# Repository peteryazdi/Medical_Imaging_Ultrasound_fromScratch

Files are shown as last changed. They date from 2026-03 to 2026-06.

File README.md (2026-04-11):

# Multi-Channel Ultrasound Imaging Device

## Overview

This repository documents the design and development of a custom ultrasound imaging platform. The system progresses from a single-channel 5 MHz analog front end to a multi-channel digital beamforming system capable of acquiring raw RF echo data, processing it on an FPGA, and producing ultrasound images.

The project covers transducer characterization, high-voltage pulse generation, low-noise receive electronics, analog-to-digital conversion, and FPGA-based signal processing.

---

## Current Status

**Rev 0 complete. Rev 1 schematic complete — PCB layout in progress.**

### Completed

- Two 5 MHz thickness-gauge transducers purchased and characterized
- Center frequency confirmed at 5.000 MHz via oscilloscope cursor measurement
- Both channels verified functional using AD2 impulse excitation
- Ring-down and cross-coupling observed through gel-coupled water path
- Rev 1 8-channel Tx/Rx schematic designed and ERC-clean in KiCad

### Rev 1 Hardware Design

The Rev 1 board is an 8-channel transmit pulser with passive receive protection, designed around the MD1213 gate driver and TC6320 complementary MOSFET pair (Microchip).

**Per channel:**
- MD1213 dual MOSFET gate driver (VQFN-12, ±5V bipolar supply)
- TC6320 N+P MOSFET pair (SOIC-8, 200V BVDSS)
- 10nF/200V AC coupling capacitors (OUTA→GP, OUTB→GN)
- 1μF/200V storage capacitors per HV rail with 1MΩ bleed resistors
- 0.47μF/16V bypass capacitors on ±5V driver supply
- Back-to-back clamp diodes (300V rated) for Tx protection
- 200Ω series resistor + back-to-back clamp diodes to GND for Rx protection
- 1MΩ DC bias resistor on Tx/Rx node
- 10kΩ pull-down on OE (outputs disabled by default)
- SMA vertical connector per channel (SMA-to-Lemo adapter for current transducers)

**Power supply (bench supply fed via screw terminals):**
- ±100V HV rails: 10μF electrolytic + 1μF ceramic + 1MΩ bleed per rail
- ±5V LV rails: 10μF ceramic per rail
- Dedicated GND screw terminal

**Control and I/O:**
- 2×14 pin header for FPGA connection (8× INA, INB, OE + TRIG_OUT, TRIG_IN, GND)
- 33Ω series resistors on all logic inputs
- 2×8 pin header for Rx output (8 channels with alternating GND pins)
- LED indicators: +5V power (green), +100V power (red), trigger activity (yellow), OE status (blue)

---

## Key Specifications

| Parameter | Value |
|---|---|
| Transducer frequency | 5 MHz |
| Pulse type | Bipolar, 1 cycle (200 ns) |
| HV supply range | ±5V to ±100V (variable via bench supply) |
| Number of Tx/Rx channels | 8 |
| MOSFET breakdown voltage | 200V (TC6320) |
| Gate drive swing | ±5V (10V total, AC coupled) |
| Rise time (500pF load) | ~8 ns |
| Peak current (100V, 7Ω RDS) | 14.3A instantaneous |
| Rx clamp voltage | ±0.7V |
| Dead zone (200Ω Rx series) | < 0.1 mm |
| Max imaging depth at 7700 Hz PRF | 10 cm |
| Axial resolution (theoretical) | 0.154 mm |
| Power dissipation per TC6320 | ~17 mW |

---

## Development Roadmap

| Revision | Scope | Status |
|---|---|---|
| Rev 0 | Transducer characterization, initial impulse testing | Complete |
| Rev 1 | 8-channel Tx pulser + passive Rx protection, scope-based echo measurement | Schematic complete, PCB layout in progress |
| Rev 2 | Multi-channel Rx analog chain (LNA, bandpass filter, TGC) on separate board | Planned |
| Rev 3 | ADC integration, digitization of RF echo data | Planned |
| Rev 4 | FPGA DSP pipeline: filtering, envelope detection, delay-and-sum beamforming | Planned |
| Rev 5 | A-scan and B-scan visualization, phantom imaging | Planned |

---

## Hardware

### Transducers
- 5 MHz thickness-gauge transducers (Amazon, 2 units)
- Lemo connectors, connected via SMA-to-Lemo adapter cables
- Used for both Tx and Rx in pitch-catch configuration

### Test Equipment
- Digilent Analog Discovery 2 (AD2) — initial low-voltage impulse source
- Tektronix TDS 2014 oscilloscope — waveform capture and measurement
- Ultrasound coupling gel

---

## Physics Reference

| Quantity | Formula | Value at 5 MHz |
|---|---|---|
| Wavelength | λ = c / f | 0.308 mm |
| Axial resolution | c / (2f) per cycle | 0.154 mm |
| Depth from echo time | d = ct / 2 | 0.77 mm/μs |
| Max PRF | c / (2 × d_max) | 7700 Hz at 10 cm |
| Attenuation | ~0.5 dB/cm/MHz | 2.5 dB/cm |
| Sound speed (soft tissue) | — | 1540 m/s |

---

## Safety

This is an educational project, not a certified medical device. The system is not intended for diagnostic or clinical use. High-voltage circuits require appropriate safety practices. All testing is performed on phantoms, water-path setups, and non-clinical targets.

---

## Author

Peter Yazdi — peteryazdi@gmail.com

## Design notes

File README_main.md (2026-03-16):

# Multi-Channel Ultrasound Imaging Device

## Overview

This repository documents the design and development of an ultrasound imaging platform intended for **educational purposes**. The long-term goal is to progress from a **single-channel 5 MHz analog ultrasound front end** to a **multi-channel digital beamforming system** capable of capturing raw radio-frequency (RF) echo data, transferring that data into an FPGA, and ultimately producing a visual ultrasound image.

This project is motivated by an interest in:

- medical imaging physics
- piezoelectric transducers and wave propagation
- analog front-end design for weak, high-frequency signals
- high-voltage pulse generation
- analog-to-digital conversion at ultrasound frequencies
- FPGA-based signal processing and beamforming
- end-to-end imaging system architecture

The project is intentionally staged so that each revision builds practical understanding of a specific subsystem before the next level of complexity is introduced. The first milestone is not full imaging, but rather a **working single-channel transmit/receive analog chain up to the ADC**.

---

## Project Purpose

Modern ultrasound imaging systems are complex, highly integrated platforms that bring together acoustics, high-voltage excitation, low-noise analog electronics, high-speed data acquisition, digital signal processing, and image formation algorithms. This project is driven by the goal of understanding and developing these core subsystems from first principles rather than treating medical ultrasound as a closed, inaccessible technology. The purpose of this repository is to serve as a technical foundation for the physics, engineering, and implementation of a medical imaging ultrasound device. As development progresses, the relevant branches will contain simulations, hardware schematics, firmware, software, and supporting documentation needed to study, build, and refine the system.

---

## Physics Background

## 1. What Ultrasound Is

Ultrasound refers to acoustic waves above the range of human hearing. In imaging systems, ultrasound commonly operates in the megahertz range. These are **longitudinal pressure waves** that propagate through matter by alternating regions of compression and rarefaction.

For soft tissue, a standard approximation for sound speed is:

```text
c ≈ 1540 m/s
```

The wavelength of ultrasound is related to frequency by:

```text
λ = c / f
```

So for a 5 MHz wave in soft tissue:

```text
λ ≈ 1540 / 5,000,000 ≈ 0.308 mm
```

That small wavelength is one of the reasons ultrasound can resolve relatively fine structures.

### Why frequency matters

Frequency is one of the most important design choices in ultrasound.

- **Higher frequency** gives better spatial resolution.
- **Lower frequency** penetrates deeper into material or tissue.

This project is beginning at **5 MHz** because it is a practical frequency for learning high-frequency analog design while still being low enough to work with relatively accessible components and transducers.

---

## 2. Acoustic Impedance and Echo Formation

Ultrasound imaging works because sound reflects at boundaries where material properties change.

The key parameter is **acoustic impedance**:

```text
Z = ρc
```

where:

- `ρ` is material density,
- `c` is sound speed in that material.

When an ultrasonic wave hits a boundary between two materials with different impedances, some energy is transmitted and some is reflected. A larger impedance mismatch produces a stronger reflection.

This is why interfaces such as:

- gel to skin,
- soft tissue to bone,
- soft tissue to air,

produce very different echo strengths.

### Reflection coefficient

For normal incidence, the reflected intensity fraction is:

```text
R = ((Z2 - Z1) / (Z2 + Z1))^2
```

This principle is central to imaging. The transducer sends a pulse, listens for returning echoes, and the **arrival time** of those echoes reveals depth.

### Time-of-flight depth estimation

If an echo is received after time `t`, then the reflector depth is approximately:

```text
d = ct / 2
```

The factor of 2 is present because the wave must travel to the target and back.

---

## 3. Piezoelectric Transducers

Ultrasound transducers are based on the **piezoelectric effect**.

A piezoelectric material can:

- mechanically deform when a voltage is applied,
- generate a voltage when mechanically deformed.

That means the same physical element can act as both:

- a **transmitter** of ultrasound,
- a **receiver** of echoes.

When driven electrically, the transducer vibrates and launches an acoustic wave into the medium. When an echo returns, the incoming pressure wave deforms the element and creates a measurable electrical signal.

In practice, a transducer is not an ideal source. It has:

- a resonant frequency,
- finite bandwidth,
- mechanical ringing,
- electrical capacitance,
- coupling losses,
- sensitivity limits,
- dependence on backing, damping, and matching layers.

---

## 4. Why Coupling Gel Matters

Air is a very poor acoustic coupling medium for most ultrasound applications because the impedance mismatch between air and solids/soft tissue is extreme. Much of the acoustic energy reflects immediately at an air gap.

Ultrasound gel is used to reduce that mismatch by replacing trapped air with a material that transmits sound much more effectively.

In this project, gel will be used for:

- improving contact between probe and test object,
- reducing front-surface losses,
- making echo experiments more repeatable.

---

## 5. Ringing, Pulses, and Resonance

A transducer is generally not driven with continuous AC for pulse-echo imaging. Instead, it is usually excited by a **very short high-voltage pulse** or a **very short burst**. That brief excitation causes the piezoelectric element to ring near its resonant frequency.

This is important:

- the **transmit circuit** does not need to output a long 5 MHz sine wave,
- instead, it needs to produce a fast, energetic excitation that launches a short ultrasonic pulse,
- after that, the system should quickly stop driving and begin listening.

A shorter transmit event generally helps produce a shorter acoustic pulse, which improves **axial resolution**. However, excessive ringing can make it harder to hear shallow echoes right after transmit.

---

## 6. A-Scan, B-Scan, and Beamforming

Ultrasound images are built from echoes.

### A-scan

An A-scan is the most basic ultrasound measurement. It shows echo amplitude versus time, or equivalently versus depth. This is the first imaging-style output this project should aim to obtain.

### B-scan

A B-scan is formed by collecting many A-scans across different lateral positions and mapping echo amplitude to brightness. This creates a 2D grayscale image.

At early stages, B-scan data can be obtained by:

- mechanically moving a single probe,
- or later by using a multi-element array.

### Beamforming

Beamforming is the process of delaying and summing signals from multiple elements to steer and focus the effective beam electronically. This is one of the major long-term digital goals of the project and the reason an FPGA is planned for later revisions.

---

## Engineering Concepts Being Applied

## 1. High-Voltage Transmit Pulse Generation

The transducer must be excited strongly enough to launch a detectable acoustic pulse. Because piezoelectric elements are relatively stiff electromechanical devices, transmit performance often benefits from fast, high-voltage pulses.

The transmit side of this project will investigate:

- how to generate a short, clean excitation pulse,
- how large that pulse must be for the purchased probe,
- whether a unipolar or bipolar pulser is more appropriate later,
- how to keep transmit energy from overwhelming the receive chain.

### Initial design philosophy

For early revisions, the focus is not yet on a production-grade pulser, but on a controlled experimental pulser that can:

- start at lower voltages,
- be measured safely on an oscilloscope,
- be increased gradually,
- and be correlated with received echo quality.

Because the transducer has no accessible full datasheet, the transmit voltage should not be assumed. It should be characterized experimentally.

---

## 2. Tx/Rx Switching

In many ultrasound systems, the same element is used for both transmission and reception. In that case, a **Tx/Rx switch** is required to:

- connect the transducer to the high-voltage pulser during transmit,
- isolate the low-noise receive path from the transmit pulse,
- reconnect the transducer to the receiver immediately after transmit.

For this project, an important practical note is that the currently purchased 5 MHz probe may already expose separate transmit and receive leads, as is common with some thickness-gauge-style probes. If that is confirmed experimentally, then the first revision may not require a traditional Tx/Rx switch.

That would simplify Rev 1 significantly and allow earlier focus on analog receive design.

---

## 3. Low-Noise Amplification (LNA)

Echoes received from a transducer are often very small compared with the transmit event that created them. The receive chain must recover weak high-frequency signals without burying them in circuit noise.

A **low-noise amplifier** is used near the front end to:

- boost very small signals early,
- improve signal-to-noise ratio,
- preserve weak echoes before later processing stages.

A good receive front end needs more than gain. It also needs:

- enough bandwidth for 5 MHz operation,
- low input-referred noise,
- stability,
- protection against overload,
- good power-supply decoupling,
- careful grounding and layout.

This project will study not only which amplifier topology is appropriate, but also how much gain should be distributed across stages.

---

## 4. Band-Pass Filtering

A receive signal contains not only useful echoes but also:

- electrical feedthrough from the transmit event,
- broadband noise,
- out-of-band interference,
- ringing and parasitic response.

A **band-pass filter** centered around the probe’s effective operating band helps:

- suppress low-frequency drift,
- suppress high-frequency noise,
- isolate the echo band of interest,
- improve downstream ADC usage.

In this project, the filter design should eventually be informed by measured probe behavior rather than assumed nominal behavior.

---

## 5. Time Gain Compensation (TGC)

As ultrasound travels deeper into a medium, echo amplitude strength tends to decrease due to attenuation and spreading losses. A fixed-gain receiver may therefore represent shallow echoes well while burying deeper echoes in noise.

**Time Gain Compensation (TGC)** is a depth-dependent gain strategy. It increases gain as time passes after transmit so that later, deeper echoes are amplified more than early echoes.

Why this matters:

- shallow reflectors often produce strong echoes,
- deeper reflectors often produce much weaker echoes,
- without TGC, the dynamic range of the image can be poorly balanced.

---

## 6. Analog-to-Digital Conversion (ADC)

The ADC is the bridge between the analog and digital halves of the system.

Its job is to sample the RF echo waveform with enough:

- speed,
- resolution,
- timing integrity,
- and channel consistency.

### Why the ADC matters so much

If the sampling rate is too low, the RF waveform will be lost or aliased.
If the resolution is too low, weak echoes may disappear into quantization noise.
If clock quality is poor, timing jitter can significantly degrade measurements.

## 7. FPGA Processing

A microcontroller is useful for many embedded tasks, but high-speed multi-channel ultrasound processing rapidly becomes a parallel data problem.

An FPGA is attractive because it can:

- capture multiple high-speed digital streams in parallel,
- implement deterministic timing,
- apply channel delays for beamforming,
- perform filtering and envelope detection,
- support custom imaging pipelines.

---

## Proposed System Architecture

The long-term signal path of the project is expected to resemble:

```text
Transducer(s)
   → transmit pulser / Tx-Rx switching
   → receive protection
   → low-noise amplification
   → band-pass filtering
   → optional variable gain / TGC
   → ADC
   → FPGA capture and DSP
   → beamforming / envelope detection / scan conversion
   → host PC or display visualization
```

---

## Development Roadmap

The roadmap below reflects the intended progression of the project and is expected to evolve as real hardware data is collected.

## Rev 0 — Probe Characterization

Before committing to a final analog architecture, the purchased probe should be characterized experimentally.

### Objectives

- identify the wiring and determine whether Tx and Rx lines are truly separate,
- verify continuity and basic electrical behavior,
- apply low-voltage test excitation first,
- observe whether one transducer can excite the other in a controlled setup,
- estimate center frequency and ringing behavior on the oscilloscope,
- determine how strongly the probe couples through gel and simple test media,
- build confidence that the purchased hardware actually functions.

### Why this revision matters

This is the best way to avoid repeating a common failure mode from earlier ultrasound prototyping work: building too much circuitry around an unverified transducer.

---

## Rev 1 — Single-Channel Analog Front End Up to the ADC node

This is the first major hardware revision.

### Goals

- build a single-channel 5 MHz transmit circuit,
- excite the probe using a short high-voltage pulse,
- use the same physical probe housing for transmit and receive,
- exploit separate Tx/Rx leads if the probe already provides them,
- design a receive chain with:
  - input protection,
  - low-noise amplification,
  - band-pass filtering,
  - optional gain staging,
- produce a clean analog signal suitable for digitization (right up to the ADC)

### Key notes

- The transmit source should be a **short pulse**, not continuous AC drive.
- The transmit voltage must be determined experimentally because the probe lacks a reliable datasheet.
- Breadboarding high-frequency analog receive stages is likely to be unreliable; early PCB or at least very compact construction is preferred.
- If separate Tx and Rx leads are confirmed, a conventional Tx/Rx switch can be deferred.

### Expected output of Rev 1

- repeatable excitation waveform,
- measurable receive waveform,
- known gain structure,
- scoped analog echo response,
- candidate signal ready for digitization.

---

## Rev 1.5 — Measurement and Test Infrastructure

### Goals

- create repeatable test targets and phantoms,
- define standard oscilloscope measurement procedures,
- record pulse width, ringing time, noise floor, and echo amplitude,
- save captured waveforms for offline analysis,
- build scripts for plotting time-domain response.

### Why this should exist

A measurement workflow is as important as the circuit itself. Without repeatable tests, later changes in gain, filtering, layout, or transmit pulse shape will be difficult to compare objectively.

---

## Rev 2 — Multi-Channel-Capable Analog Expansion

Once the single-channel path is trusted, the analog architecture should begin evolving toward multi-channel scalability.

### Goals

- redesign the single-channel analog path with replication in mind,
- evaluate how power, grounding, and shielding scale across channels,
- preserve consistent gain and bandwidth across channels,
- consider whether separate daughterboards or modular front-end blocks improve debugging,
- maintain compatibility with later high-speed ADC integration.

### Design philosophy

Even if only one or two channels are populated initially, the analog architecture should be able to support multi-channel use.

---

## Rev 3 — ADC Integration

This revision introduces real digitization.

### Single-channel target

- choose an ADC appropriate for 5 MHz RF sampling,
- validate sample quality,
- confirm timing, logic levels, and data extraction,
- save raw RF data for offline analysis.

### Multi-channel target

- transition from one sampled channel to multiple synchronized channels,
- ensure the data format and interface can scale toward FPGA capture,
- verify that the communication architecture does not become the system bottleneck.

### Expected output

- stored digital RF traces,
- verified timing relationship between transmit and sampled receive data,
- understanding of data throughput requirements.

---

## Rev 4 — FPGA Communication and Beamforming Foundations

This stage includes looking into communication protocals and what is the appropiate peripheral for this project. After there will be FPGA programming to allow for beamforming the incoming raw RF data. 

### Goals

- establish reliable communication between ADC and FPGA,
- implement raw sample capture pipelines,
- buffer and move data correctly,
- begin digital filtering and basic signal conditioning,
- build the foundations for delay-and-sum beamforming,
- learn how raw RF data becomes an image pipeline.

### Why FPGA here

By this point, the project is no longer only analog electronics. It becomes a real-time digital system problem, and the FPGA becomes central to scaling the platform into a true imaging device.

---

## Rev 5 — Visualization

This stage turns measured and processed data into something interpretable.

### Goals

- visualize A-scan data first,
- progress toward B-scan style images,
- display results on a host computer or dedicated display,
- compare raw RF, envelope-detected, and beamformed outputs,
- build intuition for what the system is actually measuring.

This stage represents the transition from “ultrasound electronics” to “ultrasound imaging.”

---

## Branching and Repository Philosophy

This repository is expected to evolve using multiple development branches.

The structure will be the following:

- `main` will hold general readme
- `theory` will involve the theory behind the phsyics and engineering concepts required to understand this project
- `simulations/testing` will involve all simulations and tests with results during development
- `hardware` will involve hardware schematics and information of current status of project
- `software/firmware` will involve all SW and FW needed for project

To see the revisions stage by stage, there will be the following branches involving all relevant data:

- `rev0_characterization`
- `rev1_single_channel_analog`
- `rev2_multi_channel_analog`
- `rev3_adc_integration`
- `rev4_fpga_pipeline`
- `rev5_visualization`

This would allow another student or builder to walk through the project historically and understand how the design matured from one stage to the next.

---

## Safety and Scope

This is an educational engineering project, not a certified medical device.

Important scope notes:

- this repository is not intended for diagnostic or clinical use,
- high-voltage pulsing requires careful safety practices,
- analog front-end circuits can be damaged easily by poor grounding or excessive transmit energy,
- early testing should be performed on phantoms, water-path setups, or simple non-clinical targets.

---

## Repository Status

Current status: **planning and architecture phase**.

This README will be updated as the project progresses to include:

---

## Author

**Peter Yazdi**

For any questions, please feel free to email me at :  peteryazdi@gmail.com

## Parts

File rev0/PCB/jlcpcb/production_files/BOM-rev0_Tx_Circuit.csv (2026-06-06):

Comment | Designator | Footprint | LCSC | Quantity
LED_GREEN | D4 | LED_D3.0mm |  | 1
SMA Vertical | J8 | SMA_Amphenol_132134-10_Vertical |  | 1
470 ohm, 0.25W | R11 | R_Axial_DIN0207_L6.3mm_D2.5mm_P10.16mm_Horizontal |  | 1
GND | INB_GND_TP2 | TestPoint_THTPad_D1.5mm_Drill0.7mm |  | 1
TX_Node_1 | TX_1_TP1 | TestPoint_THTPad_D1.5mm_Drill0.7mm |  | 1
TC6320 | Q2 | SOIC-8_3.9x4.9mm_P1.27mm |  | 1
GND | TRIG_OUT_GND_TP1 | TestPoint_THTPad_D1.5mm_Drill0.7mm |  | 1
LED_GREEN | D1 | LED_D3.0mm |  | 1
LED_GREEN | D6 | LED_D3.0mm |  | 1
HV_N | HV_N_TP1 | TestPoint_THTPad_D1.5mm_Drill0.7mm |  | 1
1N5819 | D7 | D_DO-41_SOD81_P10.16mm_Horizontal |  | 1
1uF / 200V | C4 | C_1210_3225Metric |  | 1
470 ohm, 0.25W | R27 | R_Axial_DIN0207_L6.3mm_D2.5mm_P10.16mm_Horizontal |  | 1
Jumper_2pin | JP2 | PinHeader_1x02_P2.54mm_Vertical |  | 1
100K, 0.25W | R28 | R_Axial_DIN0207_L6.3mm_D2.5mm_P10.16mm_Horizontal |  | 1
HV_P | HV_P_TP1 | TestPoint_THTPad_D1.5mm_Drill0.7mm |  | 1
INB | INB_TP2 | TestPoint_THTPad_D1.5mm_Drill0.7mm |  | 1
1uF/250V | C11 | C_1210_3225Metric |  | 1
DRV_P5V | LV_P_TP1 | TestPoint_THTPad_D1.5mm_Drill0.7mm |  | 1
TC6320 | Q1 | SOIC-8_3.9x4.9mm_P1.27mm |  | 1
10K | R16 | R_0805_2012Metric |  | 1
10K | R9 | R_Axial_DIN0207_L6.3mm_D2.5mm_P10.16mm_Horizontal |  | 1
10K | R36 | R_0805_2012Metric |  | 1
GND | INA_GND_TP2 | TestPoint_THTPad_D1.5mm_Drill0.7mm |  | 1
MURS160 | D5 | D_SMA |  | 1
Screw_Terminal_01x02 | J3 | TerminalBlock_Phoenix_MKDS-3-2-5.08_1x02_P5.08mm_Horizontal |  | 1
Screw_Terminal_01x02 | J1 | TerminalBlock_Phoenix_MKDS-3-2-5.08_1x02_P5.08mm_Horizontal |  | 1
1uF/250V | C14 | C_1210_3225Metric |  | 1
Jumper_2pin | JP1 | PinHeader_1x02_P2.54mm_Vertical |  | 1
10uF/16V | C19 | CP_Radial_D5.0mm_P2.50mm |  | 1
1uF/250V | C17 | C_1210_3225Metric |  | 1
10nF/200V | C15 | C_0805_2012Metric |  | 1
10K | R13 | R_0805_2012Metric |  | 1
MURS160 | D10 | D_SMA |  | 1
Conn_02x05_Odd_Even | J5 | PinHeader_2x05_P2.54mm_Vertical |  | 1
10nF/200V | C9 | C_0805_2012Metric |  | 1
TX_Node_2 | TX_2_TP1 | TestPoint_THTPad_D1.5mm_Drill0.7mm |  | 1
10nF/200V | C12 | C_0805_2012Metric |  | 1
10K | R12 | R_0805_2012Metric |  | 1
DCWN03_05 | U3 | DCWN03_DIP24_8PIN |  | 1
10uF/200V | C1 | CP_Radial_D10.0mm_P5.00mm |  | 1
DRV_N5V | LV_N_TP1 | TestPoint_THTPad_D1.5mm_Drill0.7mm |  | 1
10uF/200V | C2 | CP_Radial_D10.0mm_P5.00mm |  | 1
SMA Vertical | J9 | SMA_Amphenol_132134-10_Vertical |  | 1
TRIG_OUT | TRIG_OUT_TP1 | TestPoint_THTPad_D1.5mm_Drill0.7mm |  | 1
INB | INB_TP1 | TestPoint_THTPad_D1.5mm_Drill0.7mm |  | 1
INA | INA_TP2 | TestPoint_THTPad_D1.5mm_Drill0.7mm |  | 1
GND | INB_GND_TP1 | TestPoint_THTPad_D1.5mm_Drill0.7mm |  | 1
MD1213 | U1 | MD1213_VQFN12_4x4_P0.8_EP1.7x1.7 |  | 1
0.47uF/50V | C16 | C_0805_2012Metric |  | 1
1uF/250V | C21 | C_1210_3225Metric |  | 1
GND | INA_GND_TP1 | TestPoint_THTPad_D1.5mm_Drill0.7mm |  | 1
10nF/200V | C18 | C_0805_2012Metric |  | 1
GND | TX_2_GND_TP1 | TestPoint_THTPad_D1.5mm_Drill0.7mm |  | 1
MD1213 | U2 | MD1213_VQFN12_4x4_P0.8_EP1.7x1.7 |  | 1
1N4007 | D8 | D_DO-41_SOD81_P10.16mm_Horizontal |  | 1
10K | R4 | R_Axial_DIN0207_L6.3mm_D2.5mm_P10.16mm_Horizontal |  | 1
GND | LV_N_GND_TP1 | TestPoint_THTPad_D1.5mm_Drill0.7mm |  | 1
GND | HV_P_GND_TP1 | TestPoint_THTPad_D1.5mm_Drill0.7mm |  | 1
0.47uF/50V | C7 | C_0805_2012Metric |  | 1
INA | INA_TP1 | TestPoint_THTPad_D1.5mm_Drill0.7mm |  | 1
10K | R31 | R_0805_2012Metric |  | 1
Screw_Terminal_01x02 | J4 | TerminalBlock_Phoenix_MKDS-3-2-5.08_1x02_P5.08mm_Horizontal |  | 1
MURS160 | D9 | D_SMA |  | 1
1N4007 | D3 | D_DO-41_SOD81_P10.16mm_Horizontal |  | 1
0.47uF/50V | C10 | C_0805_2012Metric |  | 1
GND | TX_1_GND_TP1 | TestPoint_THTPad_D1.5mm_Drill0.7mm |  | 1
LED_RED | D2 | LED_D3.0mm |  | 1
470 ohm, 0.25W | R30 | R_Axial_DIN0207_L6.3mm_D2.5mm_P10.16mm_Horizontal |  | 1
1ufF / 16V | C8 | C_Disc_D5.0mm_W2.5mm_P2.50mm |  | 1
Screw_Terminal_01x02 | J2 | TerminalBlock_Phoenix_MKDS-3-2-5.08_1x02_P5.08mm_Horizontal |  | 1
0.47uF/50V | C13 | C_0805_2012Metric |  | 1
1uF / 200V | C5 | C_1210_3225Metric |  | 1
GND | HV_N_GND_TP1 | TestPoint_THTPad_D1.5mm_Drill0.7mm |  | 1
MURS160 | D11 | D_SMA |  | 1
1uF / 16V | C20 | C_Disc_D5.0mm_W2.5mm_P2.50mm |  | 1
10K | R15 | R_0805_2012Metric |  | 1
GND | LV_P_GND_TP1 | TestPoint_THTPad_D1.5mm_Drill0.7mm |  | 1
1M / 0.25W | R2 | R_Axial_DIN0207_L6.3mm_D2.5mm_P10.16mm_Horizontal |  | 1
1M / 0.25W | R14 | R_Axial_DIN0207_L6.3mm_D2.5mm_P10.16mm_Horizontal |  | 1
1M / 0.25W | R32 | R_Axial_DIN0207_L6.3mm_D2.5mm_P10.16mm_Horizontal |  | 1
1M / 0.25W | R17 | R_Axial_DIN0207_L6.3mm_D2.5mm_P10.16mm_Horizontal |  | 1
1M / 0.25W | R37 | R_Axial_DIN0207_L6.3mm_D2.5mm_P10.16mm_Horizontal |  | 1
1M / 0.25W | R1 | R_Axial_DIN0207_L6.3mm_D2.5mm_P10.16mm_Horizontal |  | 1

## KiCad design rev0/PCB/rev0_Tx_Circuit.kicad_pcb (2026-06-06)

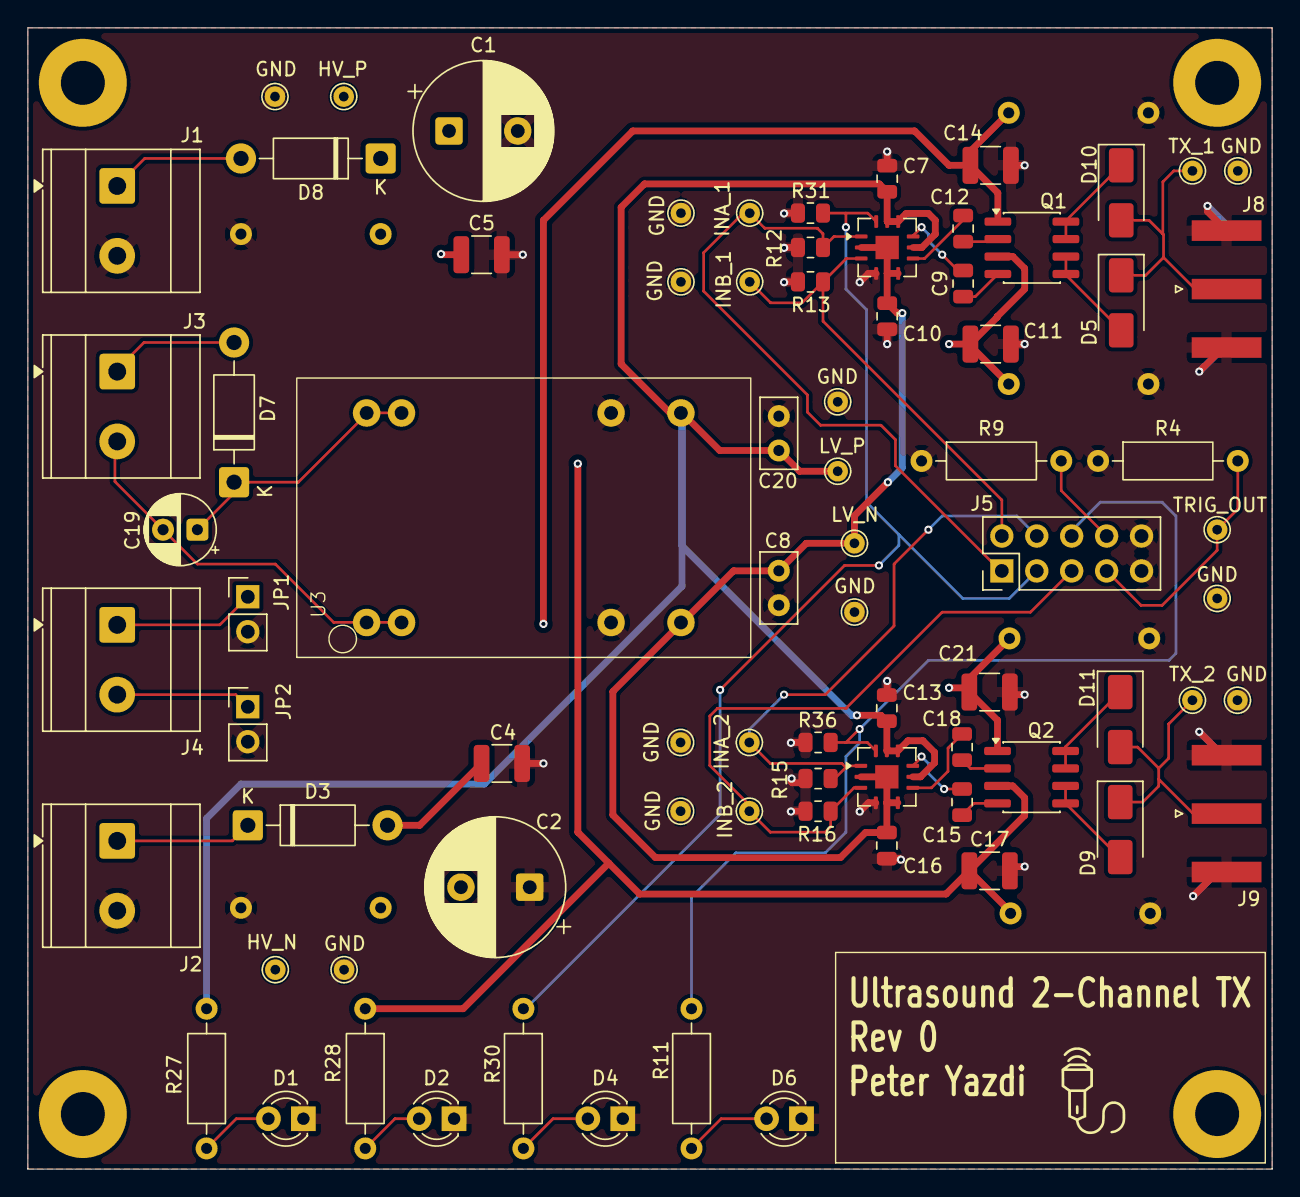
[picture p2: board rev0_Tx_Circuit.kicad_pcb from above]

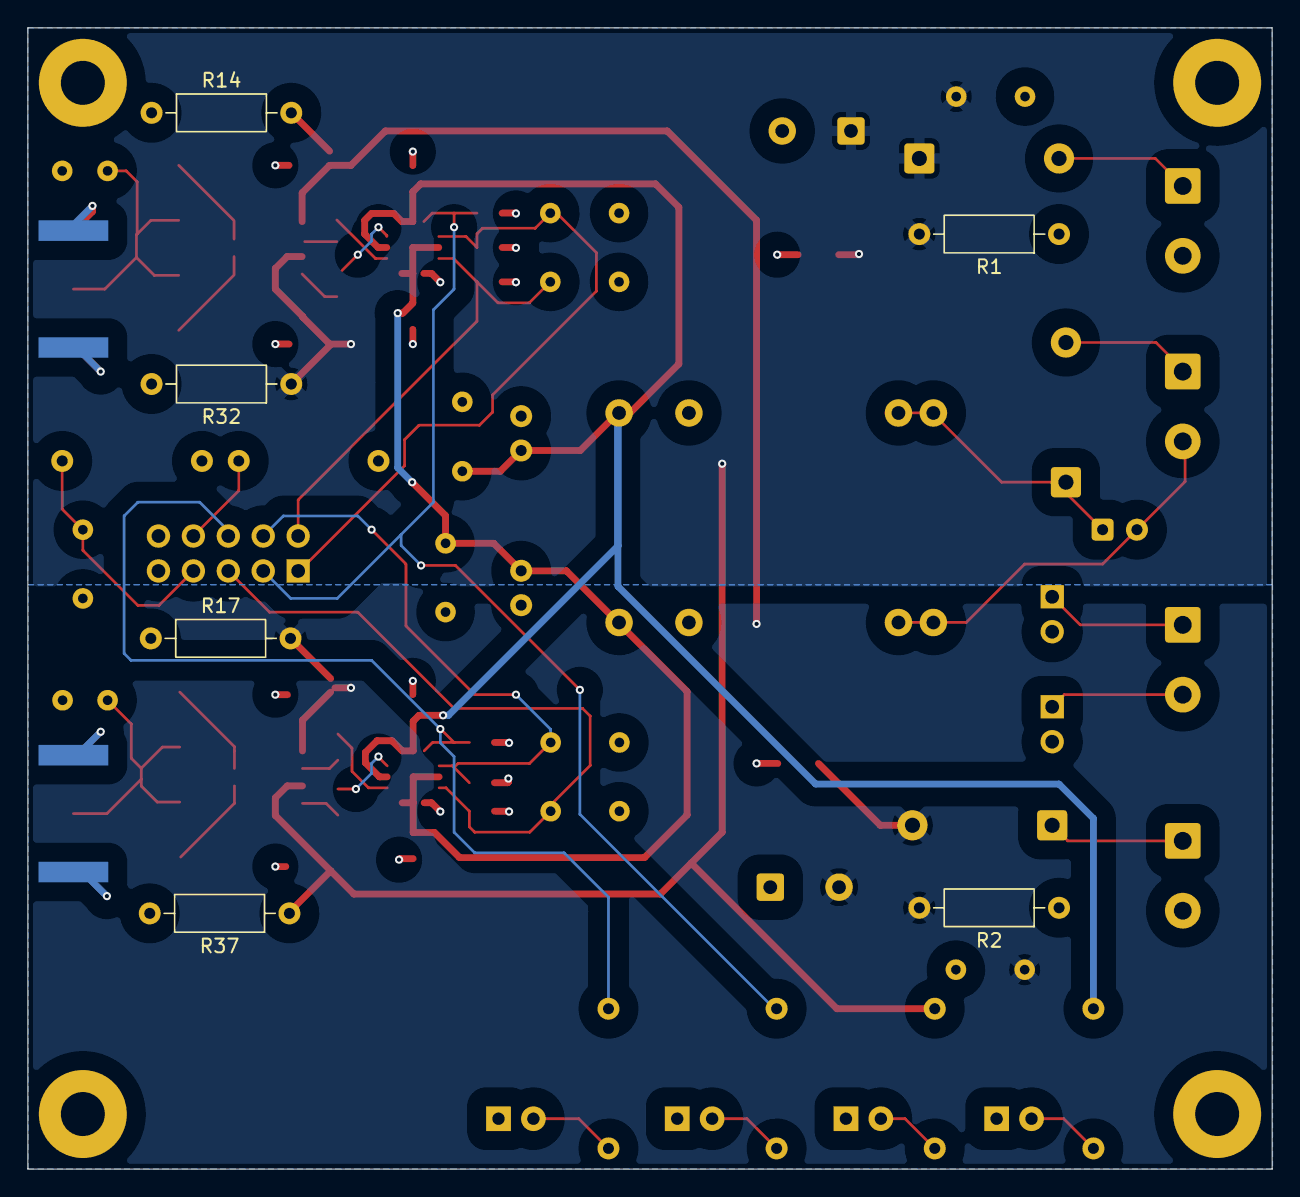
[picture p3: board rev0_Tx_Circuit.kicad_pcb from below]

Board: 4 copper layers, 90.5 x 83.0 mm, 84 parts (6 on the bottom side), 38 nets.

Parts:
C1, C2: 10uF/200V; CP_Radial_D10.0mm_P5.00mm
C4, C5: 1uF / 200V; C_1210_3225Metric
C7, C10, C13, C16: 0.47uF/50V; C_0805_2012Metric
C8: 1ufF / 16V; C_Disc_D5.0mm_W2.5mm_P2.50mm
C9, C12, C15, C18: 10nF/200V; C_0805_2012Metric
C11, C14, C17, C21: 1uF/250V; C_1210_3225Metric
C19: 10uF/16V; CP_Radial_D5.0mm_P2.50mm
C20: 1uF / 16V; C_Disc_D5.0mm_W2.5mm_P2.50mm
D1, D4, D6: LED_GREEN; LED_D3.0mm
D2: LED_RED; LED_D3.0mm
D3, D8: 1N4007; D_DO-41_SOD81_P10.16mm_Horizontal
D5, D9, D10, D11: MURS160; D_SMA
D7: 1N5819; D_DO-41_SOD81_P10.16mm_Horizontal
GND: GND; TestPoint_THTPad_D1.5mm_Drill0.7mm
GND#2, GND#3, GND#4, GND#5, GND#6, GND#7, GND#8, GND#9, GND#10, GND#11: GND; TestPoint_THTPad_D1.5mm_Drill0.7mm
HV_N: HV_N; TestPoint_THTPad_D1.5mm_Drill0.7mm
HV_P: HV_P; TestPoint_THTPad_D1.5mm_Drill0.7mm
INA_1, INA_2: INA; TestPoint_THTPad_D1.5mm_Drill0.7mm
INB_1, INB_2: INB; TestPoint_THTPad_D1.5mm_Drill0.7mm
J1, J2, J3, J4: Screw_Terminal_01x02; TerminalBlock_Phoenix_MKDS-3-2-5.08_1x02_P5.08mm_Horizontal
J5: Conn_02x05_Odd_Even; PinHeader_2x05_P2.54mm_Vertical
J8, J9: SMA Vertical; SMA_Amphenol_132289_EdgeMount
JP1, JP2: Jumper_2pin; PinHeader_1x02_P2.54mm_Vertical
LV_N: DRV_N5V; TestPoint_THTPad_D1.5mm_Drill0.7mm
LV_P: DRV_P5V; TestPoint_THTPad_D1.5mm_Drill0.7mm
Q1, Q2: TC6320; SOIC-8_3.9x4.9mm_P1.27mm
R1, R2, R14, R17, R32, R37: 1M / 0.25W; R_Axial_DIN0207_L6.3mm_D2.5mm_P10.16mm_Horizontal
R4, R9: 10K; R_Axial_DIN0207_L6.3mm_D2.5mm_P10.16mm_Horizontal
R11, R27, R30: 470 ohm, 0.25W; R_Axial_DIN0207_L6.3mm_D2.5mm_P10.16mm_Horizontal
R12, R13, R15, R16, R31, R36: 10K; R_0805_2012Metric
R28: 100K, 0.25W; R_Axial_DIN0207_L6.3mm_D2.5mm_P10.16mm_Horizontal
TRIG_OUT: TRIG_OUT; TestPoint_THTPad_D1.5mm_Drill0.7mm
TX_1: TX_Node_1; TestPoint_THTPad_D1.5mm_Drill0.7mm
TX_2: TX_Node_2; TestPoint_THTPad_D1.5mm_Drill0.7mm
U1, U2: MD1213; MD1213_VQFN12_4x4_P0.8_EP1.7x1.7
U3: DCWN03_05; DCWN03_DIP24_8PIN

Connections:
/CONTROL_IO/CH1_INA: INA_1.1 (1_1), J5.1, R12.1, U1.1 (INA)
/CONTROL_IO/CH1_INB: INB_1.1 (1_1), J5.2, R13.2, U1.3 (INB)
/CONTROL_IO/CH1_OE: J5.3, R30.1, R31.1, U1.12 (OE)
/CONTROL_IO/CH2_INA: INA_2.1 (1_1), J5.4, R15.1, U2.1 (INA)
/CONTROL_IO/CH2_INB: INB_2.1 (1_1), J5.5, R16.2, U2.3 (INB)
/CONTROL_IO/CH2_OE: J5.6, R11.1, R36.1, U2.12 (OE)
/CONTROL_IO/TRIG_IN: J5.8, R9.2
/CONTROL_IO/TX_Node_1: D5.1 (K), D10.2 (A), J8.1 (In), TX_1.1 (1_1)
/CONTROL_IO/TX_Node_2: D9.1 (K), D11.2 (A), J9.1 (In), TX_2.1 (1_1)
DRV_N5V: C8.1, C10.2, C16.2, LV_N.1 (1_1), U1.2 (VL), U1.5 (VSS1), U1.6 (VSS2), U1.13 (EP), U2.2 (VL), U2.5 (VSS1), U2.6 (VSS2), U2.13 (EP), U3.11 (-Vout)
DRV_P5V: C7.1, C13.1, C20.2, LV_P.1 (1_1), R27.1, U1.8 (VH), U1.10 (VDD2), U1.11 (VDD1), U2.8 (VH), U2.10 (VDD2), U2.11 (VDD1), U3.14 (+Vout)
GND: C1.2, C2.1, C4.1, C5.1, C7.2, C8.2, C10.1, C11.2, C13.2, C14.1, C16.1, C17.2, C20.1, C21.1, D1.1 (K), D2.1 (K), D4.1 (K), D6.1 (K), GND.1 (1_1), GND#2.1 (1_1), GND#3.1 (1_1), GND#4.1 (1_1), GND#5.1 (1_1), GND#6.1 (1_1), GND#7.1 (1_1), GND#8.1 (1_1), GND#9.1 (1_1), GND#10.1 (1_1), GND#11.1 (1_1), J1.2, J2.2, J5.9, J5.10, J8.2 (Ext), J9.2 (Ext), JP1.2 (B), JP2.2 (B), R1.1, R2.1, R4.1, R9.1, R12.2, R13.1, R14.1, R15.2, R16.1, R17.1, R31.2, R32.2, R36.2, R37.2, U1.4 (GND), U2.4 (GND), U3.9 (Common), U3.16 (Common)
HV_N: C2.2, C4.2, C14.2, C21.2, D3.2 (A), HV_N.1 (1_1), Q1.1 (SN), Q2.1 (SN), R2.2, R14.2, R17.2
HV_P: C1.1, C5.2, C11.1, C17.1, D8.1 (K), HV_P.1 (1_1), Q1.3 (SP), Q2.3 (SP), R1.2, R28.1, R32.1, R37.1
unnamed: D1.2 (A), R27.2
unnamed: D2.2 (A), R28.2
unnamed: D3.1 (K), J2.1
unnamed: D4.2 (A), R30.2
unnamed: D5.2 (A), Q1.5 (DP), Q1.6 (DP)
unnamed: D6.2 (A), R11.2
unnamed: D7.2 (A), J3.1
unnamed: C19.1, D7.1 (K), U3.22 (+Vin), U3.23 (+Vin)
unnamed: D8.2 (A), J1.1
unnamed: D9.2 (A), Q2.5 (DP), Q2.6 (DP)
unnamed: D10.1 (K), Q1.7 (DN), Q1.8 (DN)
unnamed: D11.1 (K), Q2.7 (DN), Q2.8 (DN)
unnamed: C19.2, J3.2, U3.2 (-Vin), U3.3 (-Vin)
unnamed: J4.1, JP1.1 (A)
unnamed: J4.2, JP2.1 (A)
unnamed: J5.7, R4.2, TRIG_OUT.1 (1_1)
unnamed: C12.2, Q1.2 (GN)
unnamed: C9.2, Q1.4 (GP)
unnamed: C18.2, Q2.2 (GN)
unnamed: C15.2, Q2.4 (GP)
unnamed: C9.1, U1.9 (OUTA)
unnamed: C12.1, U1.7 (OUTB)
unnamed: C15.1, U2.9 (OUTA)
unnamed: C18.1, U2.7 (OUTB)

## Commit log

2026-06-06 rev0 PCB in progress
    [channel_cell.kicad_sch, control_io.kicad_sch, hv_power.kicad_sch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]
2026-06-06 Restore project files; reorganize Rev0 PCB layout, add JLC production files
    [BOM-rev0_Tx_Circuit.csv, channel_cell.kicad_sch, control_io.kicad_sch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]
